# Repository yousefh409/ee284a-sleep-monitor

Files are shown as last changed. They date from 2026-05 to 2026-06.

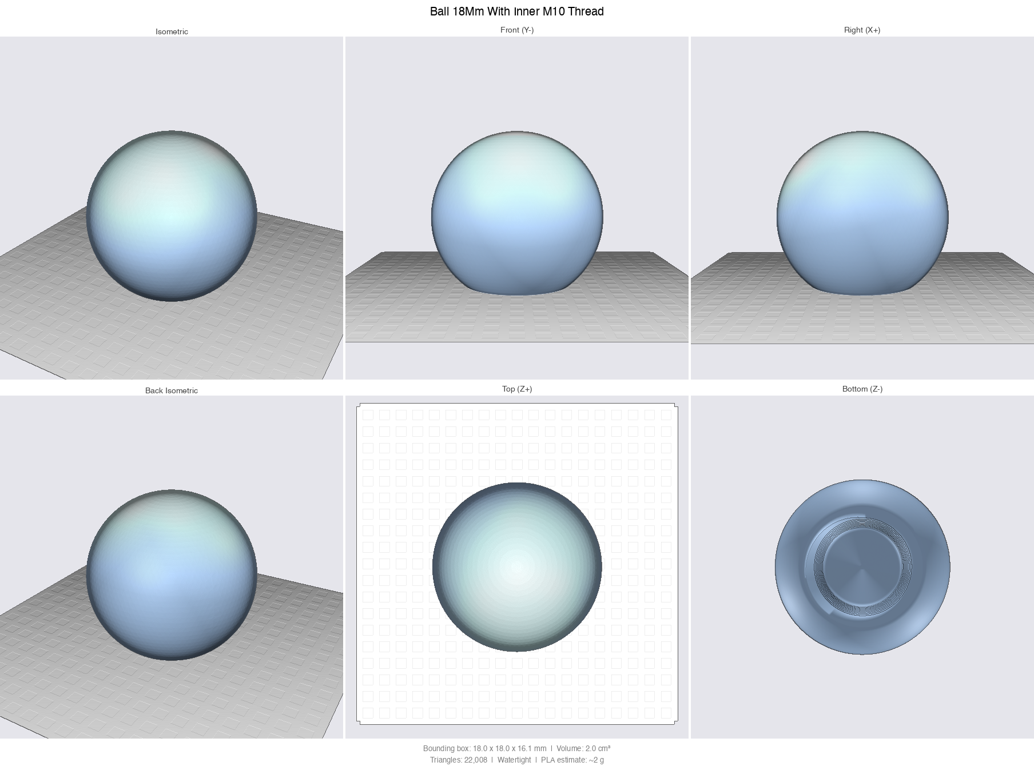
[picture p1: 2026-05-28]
cad/joint/Ball 18mm with inner M10 thread_preview.png

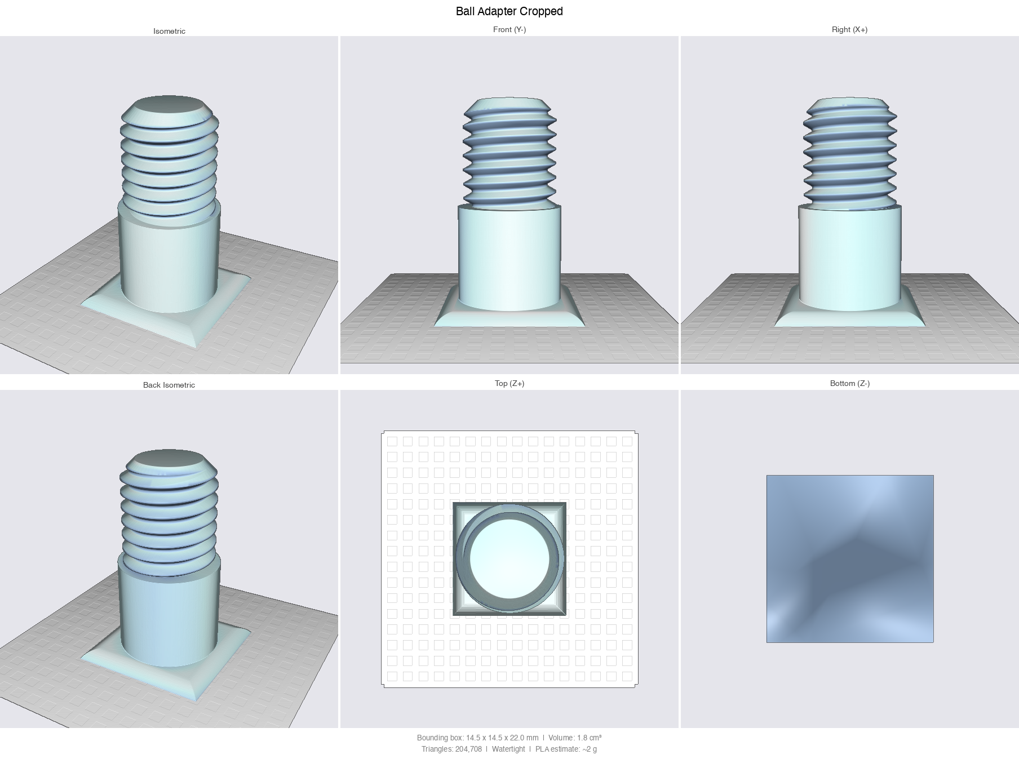
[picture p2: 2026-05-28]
cad/ball_adapter_cropped_preview.png

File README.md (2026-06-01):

# Sleep Monitor

**Contactless bedside sleep tracker that explains *why* you slept badly — no wearable required.**

A 60 GHz mmWave radar watches your breathing, heart rate, and sleep stages from across the room while environmental sensors log everything that could wake you. Each arousal gets tagged with its likely cause, and Claude writes you a morning briefing.

<p>
  
  
  
  
  
  
  
  
</p>

---

## Why

A third of adults sleep poorly, but consumer trackers demand nightly wearable compliance and still can't tell you *why* you woke up. This node sits on the nightstand, sees nothing but radar reflections and room conditions, and turns a night of raw telemetry into a plain-English explanation by morning.

## What it does

- **Contactless sleep staging** — awake / light / deep, with no wearable, from 0.4–2.5 m away
- **Live vitals in bed** — breathing rate and heart rate straight off the radar
- **Per-minute environment log** — temperature, humidity, pressure, gas/VOC air quality, noise (dB SPL), light
- **Annotated wake events** — every arousal tagged with its likely cause: noise spike, temperature drift, or light
- **AI morning briefing** — Claude turns the night into a sleep score, headline, wake-cause list, and 1–3 recommendations
- **Edge-side audio privacy** — raw mic samples never leave the device; only a computed dB SPL value is published

## How it works

```
USB-C wall ──> [Feather V2 ESP32] ──5V──> [C1001 60 GHz mmWave radar]
                       │  3V3
                       ├──I2C──> [BME680  temp/humidity/pressure/gas]
                       ├──ADC──> [SPW2430 mic  → on-device RMS → dB SPL]
                       └──ADC──> [Photoresistor  light]
                       │
                       └──Wi-Fi / MQTT / TLS──> [HiveMQ Cloud]
                                                      │
                                                      ▼
                                       [Next.js app on Railway]
                                         ├── MQTT subscriber (instrumentation.ts)
                                         ├── Postgres (telemetry / nights / reports)
                                         ├── Wake detection + correlation engine
                                         ├── Claude API → morning briefing
                                         └── Dashboard (Chart.js timeline)
```

The ESP32 publishes a ~350-byte JSON snapshot every 30 s. A single Next.js app subscribes over TLS, stores each row, and runs in-memory wake detection. When a sleep session ends it bundles the night, sends it to Claude, and stores a structured report the dashboard renders the next morning.

## Tech stack

| Layer | Stack |
|---|---|
| Firmware | PlatformIO · Arduino · ESP32 Feather V2 · PubSubClient · ArduinoJson |
| Sensing | DFRobot C1001 mmWave (UART) · BME680 (I²C) · SPW2430 mic + photoresistor (ADC) |
| Transport | MQTT over TLS · HiveMQ Cloud |
| Backend | Next.js 15 App Router · TypeScript · Postgres |
| AI | Anthropic Claude API (Haiku 4.5) with prompt caching |
| Dashboard | React · Tailwind CSS · Chart.js |
| Hosting | Railway (app + Postgres add-on) |

## Hardware (single node)

- Adafruit ESP32 Feather V2 (USB-C wall powered)
- DFRobot C1001 60 GHz mmWave radar — presence, sleep stages, breathing, heart rate
- BME680 — temperature, humidity, pressure, gas/VOC
- SPW2430 analog MEMS microphone + photoresistor (10 kΩ pull-down)
- 3D-printed enclosure + ball-joint wall mount (6 printed parts, see [PRINT-PLAN.md](PRINT-PLAN.md))

## Layout

| Folder | What |
|---|---|
| `firmware/` | PlatformIO project for the Feather V2 |
| `web/` | Next.js 15 app: MQTT subscriber + Postgres + Claude + dashboard |
| `cad/` | CadQuery scripts + STL files for the 3D-printed parts |
| `cad/final/` | The 6 STLs to print (numbered in build order) |

## Quick start

```bash
# Firmware — flash the Feather V2
cd firmware && pio run -t upload    # see firmware/README.md for config.h setup

# Web — local dev
cd web && npm install && npm run dev # see web/README.md for env vars + deploy
```

## Docs

- [PRD.md](PRD.md) — product requirements
- [TECH-SPEC.md](TECH-SPEC.md) — technical spec (firmware, MQTT, backend, dashboard)
- [DESIGN.md](DESIGN.md) — hardware design
- [WIRING.md](WIRING.md) — pin-by-pin wiring guide
- [CIRCUIT.md](CIRCUIT.md) — power + signal topology
- [PRINT-PLAN.md](PRINT-PLAN.md) — 3D print + assembly plan

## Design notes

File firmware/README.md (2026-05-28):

# Firmware

Adafruit ESP32 Feather V2 · PlatformIO · Arduino framework.

Two PlatformIO environments:

| Env | Source | What it does |
|---|---|---|
| `main` (default) | `src/main.cpp` | Production firmware: Wi-Fi → MQTT, publishes JSON to HiveMQ every 10 s. Needs `include/config.h`. |
| `sensor_test` | `src/sensor_test.cpp` | Bench test only: reads all sensors, prints one JSON line to USB serial every 1 s. No Wi-Fi, no MQTT, no config.h needed. |

## Setup (once)

Install [PlatformIO](https://platformio.org/install). VS Code extension recommended.

## Production build (main env)

```bash
cp include/config.h.example include/config.h
# edit include/config.h with Wi-Fi + HiveMQ credentials
pio run -e main -t upload
pio device monitor
```

## Sensor test (no credentials needed)

```bash
pio run -e sensor_test -t upload
pip install pyserial          # one-time
python3 serial_monitor.py     # auto-detects the port and pretty-prints
```

The `serial_monitor.py` script clears the terminal and re-renders the current sensor reading each second — easy to watch values change as you move/breathe in front of the C1001, cover the photoresistor, blow on the BME680, etc.

**Note:** the C1001 library has two hardcoded `delay(10000)` calls in its init + reset, so the first JSON line takes ~22 s after boot. Once running, JSON arrives every second.

See [../TECH-SPEC.md](../TECH-SPEC.md) for the full JSON schema.

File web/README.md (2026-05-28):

# Web

Next.js 16 (App Router) + Tailwind + Postgres + MQTT subscriber + Claude API.

Single app on Railway: MQTT subscriber runs inside `instrumentation.ts`, REST API in `app/api/`, dashboard in `app/page.tsx`.

## Local dev

1. Copy `.env.local.example` to `.env.local` and fill in credentials.
2. `npm run dev` → open `http://localhost:3000`. Schema is auto-applied on first request via `instrumentation.ts` → `lib/migrate.ts`.
3. First load redirects to `/login`. Use the password from `DASHBOARD_PASSWORD`.

## Layout

| Path | Purpose |
|---|---|
| `instrumentation.ts` | Boots the MQTT subscriber on Node.js runtime start |
| `proxy.ts` | Password gate (redirects unauthenticated requests to `/login`) |
| `lib/db.ts` | Postgres connection pool |
| `lib/mqtt.ts` | MQTT subscriber + telemetry insert + wake detection + LLM trigger |
| `lib/claude.ts` | Anthropic SDK wrapper, prompt-cached system prompt |
| `lib/schema.ts` | Postgres schema as a TS const (inlined for production) |
| `lib/migrate.ts` | Runs `SCHEMA_SQL` once on server boot (idempotent) |
| `lib/types.ts` | Shared TypeScript types |
| `app/page.tsx` | Dashboard (live panel + AI briefing + sleep-stage band) |
| `app/login/page.tsx` | Password gate UI |
| `app/api/login/route.ts` | POST `/api/login` — sets the session cookie |
| `app/api/live/route.ts` | GET `/api/live` — last 10 minutes of telemetry |
| `app/api/nights/route.ts` | GET `/api/nights` — list of past nights |
| `app/api/nights/[id]/route.ts` | GET `/api/nights/:id` — full night detail + report |
| `scripts/pub-test.mjs` | Local debug: publishes a synthetic telemetry payload to MQTT |

## Deploy to Railway

1. Push to a GitHub repo.
2. Create a Railway project, point it at this repo's `web/` folder.
3. Add the Postgres add-on. `DATABASE_URL` is auto-injected.
4. Set the rest of the env vars from `.env.local.example`.
5. Schema is auto-applied at startup; no manual migration step.

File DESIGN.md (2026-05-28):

# DESIGN: Sensor Node Hardware

**Companion to** [PRD.md](PRD.md) · **Date:** 2026-05-26

## 1. Enclosure

Wall-adhered housing with the C1001 mounted on the front via the ball-joint chain (joint plate → 18 mm ball → lock nut → cropped 3-leg adapter → L-bracket holder). Print and assembly details in [PRINT-PLAN.md](PRINT-PLAN.md).

## 2. Circuit Topology

```
USB-C wall ──> Feather V2 USB-C port
                Feather USB pin ──> C1001 (5V, GND)
                Feather 3V3 pin ──> BME680, mic, LDR
                Feather TX/RX  ──> C1001 UART
                Feather SDA/SCL ──> BME680
                Feather A2 ──> SPW2430 mic (analog)
                Feather A3 ──> Photoresistor + 10kΩ pull-down
```

No battery, no PMIC, no boost — Feather V2 directly powers everything from the USB-C wall.

## 3. Pin Map (Feather V2)

| Function | Pin | Notes |
|---|---|---|
| C1001 UART | TX / RX (Serial1) | 115200 baud; keeps USB serial free for debug |
| BME680 | SDA / SCL | I²C @ 0x77 (default, CS/SDO floating) — temp / humidity / pressure / gas |
| SPW2430 mic | A2 (ADC1) | Analog audio → onboard RMS → dB SPL |
| Photoresistor | A3 (ADC1) | With 10 kΩ pull-down |
| 5 V to C1001 | USB pin | Passthrough from USB-C wall power |

ESP32 ADC2 conflicts with Wi-Fi — both analog sensors are on ADC1 pins (A2, A3).

## 4. Open Items

- Mic dB SPL calibration constant — set during firmware bring-up by comparing to a phone SPL app under known sound levels.
- Cable routing from C1001 through the ball joint back to the breadboard — use a 4-wire cable, leave a small service loop.

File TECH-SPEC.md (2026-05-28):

# TECH-SPEC

**Project:** Contactless Sleep & Environment Monitor · **Date:** 2026-05-26
**Companion to:** [PRD.md](PRD.md) · [DESIGN.md](DESIGN.md) · [CIRCUIT.md](CIRCUIT.md) · [PRINT-PLAN.md](PRINT-PLAN.md)

## 1. Architecture

```
[Feather V2 ESP32]
   ├── C1001 mmWave (UART2)
   ├── BME680       (I2C 0x76)
   ├── SPW2430 mic  (ADC1 A2)
   └── Photoresistor(ADC1 A3)
            │
            └── Wi-Fi/MQTT/TLS ──> [HiveMQ Cloud]
                                        │
                                        ▼
                          [Next.js app on Railway]
                            ├── instrumentation.ts: MQTT subscriber
                            ├── Postgres (Railway add-on)
                            ├── Claude API (LLM analysis)
                            └── app/page.tsx: dashboard UI
```

Single Next.js app on Railway handles MQTT subscription, data storage, LLM analysis, REST API, and dashboard rendering. No separate worker, no separate frontend.

## 2. Hardware

**MCU:** Adafruit ESP32 Feather V2. USB-C wall powered. No battery, no PMIC, no boost.

**Sensors:**

| Sensor | Interface | Pin/Addr | Purpose |
|---|---|---|---|
| DFRobot C1001 60GHz mmWave | UART @ 115200 | TX2/RX2 | Presence, sleep stages, breathing, heart rate |
| BME680 | I2C @ 100kHz | 0x77 (default) | Temperature, humidity, pressure, gas/VOC resistance |
| SPW2430 MEMS mic | Analog | A2 (ADC1) | dB SPL (RMS computed on-device, raw audio never leaves) |
| Photoresistor + 10 kΩ | Analog | A3 (ADC1) | Light level |

Full wiring details in [CIRCUIT.md](CIRCUIT.md).

## 3. Firmware

**Platform:** PlatformIO, Arduino framework, `adafruit_feather_esp32_v2` board.

**Libraries:**
- `Adafruit_BME680` (+ `Adafruit_Sensor`)
- `DFRobot_HumanDetection` (C1001 driver)
- `PubSubClient` (MQTT)
- `ArduinoJson`
- `WiFiClientSecure` (TLS for HiveMQ)

**Wi-Fi credentials:** hardcoded in `firmware/include/config.h`, gitignored. Includes SSID, password, MQTT host, port, username, password, topic.

**Loop behavior:**

| Action | Cadence |
|---|---|
| Sample mic, compute 1 s RMS, update running max dB SPL | continuous |
| Read C1001 sleep composite (state, breathing, heart rate, presence) | 1 Hz |
| Read BME680 (T/H/P/gas) | 0.1 Hz (every 10 s); gas heater is 320 °C / 150 ms |
| Read photoresistor ADC | 0.1 Hz |
| Publish JSON to MQTT | every 10 s |

**Connection recovery:** Wi-Fi disconnect triggers reconnect loop. MQTT disconnect triggers reconnect loop.

## 4. MQTT

- **Broker:** HiveMQ Cloud Free (TLS, port 8883)
- **Topic:** `yousef/sleep01/telemetry`
- **QoS:** 1 (at-least-once delivery)
- **Retained:** false
- **Payload:** JSON, ~350 bytes

**JSON schema (per-minute snapshot, all values nullable if sensor not in a valid state):**

```json
{
  "t": 1735689600,
  "dev": "sleep01",

  "presence": 1,
  "in_bed": 1,
  "sleep_state": 2,
  "breathing": 16,
  "heart_rate": 62,
  "turnover": 14,
  "body_move_large": 4,
  "body_move_small": 22,
  "apnea_events": 0,

  "temp_c": 22.1,
  "humidity": 45.2,
  "pressure_hpa": 1013.2,
  "gas_ohm": 5684,
  "db_spl": 32.5,
  "light_raw": 245
}
```

| Field | Source | Units | Notes |
|---|---|---|---|
| `t` | ESP32 | unix seconds | NTP-synced |
| `presence` | C1001 composite | 0/1 | Anyone in detection cone |
| `in_bed` | C1001 `smSleepData(eInOrNotInBed)` | 0/1 | More specific than presence |
| `sleep_state` | C1001 composite | 0–3 | 0 not-in-bed, 1 awake, 2 light, 3 deep |
| `breathing` | C1001 composite `averageRespiration` | breaths/min | Recent average |
| `heart_rate` | C1001 composite `averageHeartbeat` | bpm | Recent average |
| `turnover` | C1001 composite `turnoverNumber` | count | Cumulative for current session |
| `body_move_large` | C1001 composite `largeBodyMove` | % | Recent window large-motion fraction |
| `body_move_small` | C1001 composite `minorBodyMove` | % | Recent window small-motion fraction |
| `apnea_events` | C1001 composite `apneaEvents` | count | Cumulative for current session |
| `temp_c` | BME680 | °C | |
| `humidity` | BME680 | % RH | |
| `pressure_hpa` | BME680 | hPa | |
| `gas_ohm` | BME680 | Ω | Gas/VOC sensor resistance; lower = more VOCs/contaminants |
| `db_spl` | SPW2430, RMS over 1 s | dB SPL approx | Max over last 10 s |
| `light_raw` | Photoresistor | 0–4095 | ADC raw, calibrate to lux dashboard-side |

**Session-level fields** (queried from C1001's `getSleepStatistics()` at end-of-session only, written directly to Postgres `nights` table, NOT in per-minute MQTT): `sleepQualityScore`, `sleepTime`, `wakeDuration`, `shallowSleepPercentage`, `deepSleepPercentage`, `timeOutOfBed`, `exitCount`, `turnOverCount`. These feed the AI briefing alongside the raw telemetry.

## 5. Backend (Next.js)

**Framework:** Next.js 15 App Router, TypeScript.

**MQTT subscriber:** in `instrumentation.ts`, runs once on server boot. Uses `mqtt` npm package, holds persistent TLS connection to HiveMQ. On each message: parse JSON, insert row into Postgres, run wake-detection check.

**Wake detection:** maintains in-memory state per device. A "sleep session" starts when `presence=1` AND `sleep_state >= 2` for 5 consecutive minutes. A session ends when `presence=0` for 5 consecutive minutes after such a start, or when `sleep_state` is `1` (awake) for 10 consecutive minutes after a long-enough session (>2 h). On session end: bundle the session's telemetry, send to Claude, store the report.

**Postgres schema:**

| Table | Columns |
|---|---|
| `telemetry` | id, device, ts, presence, in_bed, sleep_state, breathing, heart_rate, turnover, body_move_large, body_move_small, apnea_events, temp_c, humidity, pressure_hpa, gas_ohm, db_spl, light_raw |
| `nights` | id, device, started_at, ended_at, duration_sec, sleep_score |
| `reports` | id, night_id, headline, sleep_score, stage_pct (jsonb), vitals (jsonb), wake_events (jsonb), recommendations (jsonb), generated_at |

`telemetry` is indexed on `(device, ts)`. `nights` is indexed on `(device, started_at DESC)`.

**Claude API integration:** Anthropic SDK (`@anthropic-ai/sdk`). On wake-detection trigger:

1. Query `telemetry` rows for the night.
2. Downsample to ~1 row per minute, serialize as CSV.
3. Send to Claude Haiku 4.5 with a fixed system prompt: "You are a sleep coach analyzing one night of contactless monitor data." (Upgrade path to Sonnet 4.6 by changing one env var if Haiku output is insufficient.)
4. Parse Claude's structured JSON response.
5. Insert into `reports`.

**Prompt caching:** the system prompt + the schema description are cached (5 min TTL) so consecutive analyses pay only for new telemetry.

**REST endpoints:**

| Route | Returns |
|---|---|
| `GET /api/nights` | list of nights with date, score, headline |
| `GET /api/nights/[id]` | full night payload: report + downsampled telemetry |
| `GET /api/live` | last 10 minutes of telemetry rows |

**Auth:** simple password gate via Next.js middleware. Single password from `DASHBOARD_PASSWORD` env var. Sets a signed session cookie on success.

## 6. Dashboard

**Stack:** Next.js + React + Tailwind CSS + Chart.js. Calm health-app aesthetic.

**Page structure (`app/page.tsx`):**

1. **Top bar:** date picker dropdown (recent nights), connection status indicator (live), logout button.
2. **Live panel** (when current night ongoing): last 10 minutes of breathing, heart rate, dB, temp. Polls `/api/live` every 5 seconds.
3. **AI morning briefing card:**
   - Sleep score (big number) + headline
   - Stage breakdown (% awake / light / deep) + vitals (avg breathing, avg HR)
   - Wake events list with timestamps and environmental causes
   - 1-3 recommendations for tonight
4. **Charts (below briefing):**
   - Overnight sleep-stage band (Chart.js timeline)
   - Breathing + heart rate dual-line
   - Environmental overlay (temp, humidity, dB, light) with wake-event markers
5. **Footer:** link to PRD/repo.

**Live refresh:** `setInterval(fetch, 5000)` polling the `/api/live` endpoint.

## 7. Edge efficiency

Wall-powered means no hard runtime constraint, but the firmware still implements meaningful power-management techniques. Measured + reported as innovation #5 even without a battery.

| Technique | Behavior | Approx saving |
|---|---|---|
| ESP32 light-sleep between samples | Between sensor reads, MCU drops to ~3 mA. Wakes on RTC timer for next sample. | ~70% of MCU draw |
| Wi-Fi modem-sleep | Modem off between MQTT publishes; wakes only to TX. Keep-alive set to 60 s. | ~50% of radio draw |
| C1001 soft-stop on long absence | If `presence=0` for >30 minutes, send `stop` command over UART. Resume on next motion event. | ~100 mA → ~idle when room empty |
| BME680 forced mode | One-shot reads instead of continuous; sleeps between reads. | ~99% of BME draw between samples |
| Mic sampling burst | 1 s of 8 kHz ADC reads per 10 s, then ADC idle. | ~90% of ADC duty |

**Measured baseline target:** ~80 mA average system current (vs ~150 mA naive always-on). Not battery-critical but documents good IoT design and gives the report something concrete to point at.

## 8. Deployment

| Service | Provider | Setup |
|---|---|---|
| MQTT broker | HiveMQ Cloud Free | Signup, create free cluster, copy host + credentials |
| App + worker | Railway | `railway up` from this repo, sets PORT |
| Postgres | Railway add-on | One-click attach, `DATABASE_URL` auto-injected |

**Env vars (Railway):**
- `DATABASE_URL` (auto)
- `MQTT_HOST`, `MQTT_PORT`, `MQTT_USER`, `MQTT_PASS`, `MQTT_TOPIC`
- `ANTHROPIC_API_KEY`
- `DASHBOARD_PASSWORD`

**Local Wi-Fi config (firmware):** `firmware/include/config.h` (gitignored):
- `WIFI_SSID`, `WIFI_PASS`
- Same MQTT credentials as the Railway service uses to subscribe.

## 9. Demo plan

**Live (1 min):**
1. Power on the device. Connection state visible on the dashboard ("● streaming" indicator).
2. Walk past it, sit on a chair in front of it. Dashboard live panel shows presence flipping to 1 and breathing rate appearing.
3. Open the dashboard live panel on screen.

**Recorded (5 min):**
1. Open the date picker. Select a prior real overnight dataset.
2. Walk through the AI briefing card: sleep score, headline, wake events, recommendations.
3. Scroll to charts. Point at a wake event marker, show the environmental spike that caused it.
4. Mention all 6 innovations as they appear visually.

**Innovations recap (also on slides):**
1. New sensor type not in prior labs: C1001 60GHz mmWave radar (presence + sleep stages + breathing + heart rate onboard)
2. Multi-sensor correlation engine (radar wake events linked to env spikes ±60 s)
3. AI-driven sleep coach (Claude API auto-generates morning briefing on wake)
4. Custom consumer-facing dashboard
5. 3D-printed wall-mount enclosure + ball-joint chain (housing + L-bracket holder + cropped community joint)
6. Edge-side audio privacy (raw mic samples never leave the device; only dB SPL transmitted)
7. Edge efficiency (light-sleep, modem-sleep, C1001 soft-stop on absence; measured ~50% avg current reduction)

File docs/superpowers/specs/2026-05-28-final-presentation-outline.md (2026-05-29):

# Final Presentation Outline — Contactless Sleep & Environment Monitor

**Course:** EE284A · **Author:** Yousef Helal · **Demo day:** 2026-06-09
**Format:** 25 min total = 15 min talk + 10 min live demo + 5 min Q&A

## Framing decisions
- **Application domain:** Healthcare → eldercare (senior-living facilities).
- **Narrative arc:** introduce the large-scale eldercare vision first, then the single node actually built.
- **Talk/demo order:** deliver the full talk (slides 1–15), then go live for the demo, then Q&A. Narrative concludes before the demo so a demo hiccup can't undercut the close.

## Slide list

| # | Slide | Job |
|---|---|-----|
| 1 | Title | Contactless Sleep & Environment Monitor · eldercare framing · author · EE284A. (Optional cold-open on the statistic instead.) |
| 2 | Hook | Hard statistic — sleep as a health monitor / early-warning signal in older adults |
| 3 | Problem | Comparison table: wearables vs clinical sleep study vs cameras vs this system — only this system checks every box (compliance-free, low-cost, private, continuous) |
| 4 | Solution reveal | The single idea: passive contactless bedside monitor, nothing to wear + one value-prop line + device image |
| 5 | Eldercare vision | Node per resident room → central nursing-station dashboard + prioritized alerts; "greater than the sum of its parts" (one nurse watches a wing, cross-resident baselines, triage) |
| 6 | System architecture | N nodes → Wi-Fi → MQTT broker → cloud services (correlator + storage) → caregiver dashboard; security & management as labeled callouts |
| 7 | Node overview | Annotated hero photo of the real built device, callouts on every component |
| 8 | Hardware: radar | DFRobot C1001 60 GHz mmWave — FMCW micro-motion → breathing/heart rate + onboard sleep stages; why radar = contactless + private; UART / 5 V |
| 9 | Hardware: sensors + wiring | BME680 (I²C), SPW2430 mic (ADC), photoresistor (ADC); block/wiring diagram |
| 10 | Hardware: enclosure | 3D-printed ball-joint enclosure render with feature callouts (innovation #4) |
| 11 | Software: edge | ESP32 firmware + MQTT + on-device dB SPL (RMS); raw audio never leaves the device; per-minute JSON payload |
| 12 | Software: cloud | Correlation engine — "why you woke up": joins radar wake events with environmental spikes within ±60 s and labels the cause |
| 13 | Results: overview | Real overnight dataset on the dashboard — full-night view (sleep-stage bands + environment overlay + sleep score) |
| 14 | Results: zoom | One annotated correlated wake event |
| 15 | Innovations scorecard | 5 innovations mapped to the assignment's categories (sensor / data processing / visualization / physical design) — 4 of 5 categories hit |
| 16 | Impact + future | Short/long-term eldercare impact + honest roadmap (fall detection, multi-person beds, ML scoring, multi-node home networks) |
| — | **LIVE DEMO** | 10 min — interactive dashboard playback + live MQTT publish |
| 17 | Questions? | Shown during the 5-min Q&A after the demo |

## Five technical innovations (referenced on slide 14)
1. New sensor: C1001 60 GHz mmWave radar (onboard sleep stages + breathing + heart rate)
2. Multi-sensor cloud correlation engine (wake event ↔ environmental cause)
3. Custom web dashboard (overnight timeline + environment overlay + annotated wake causes)
4. 3D-printed wall-mount enclosure with ball-joint aim
5. Edge-side audio privacy (on-device RMS → dB SPL; no raw audio transmitted)

## Rubric coverage check
- Application domain + proposed system → slides 1–5
- Motivation + background → slides 2–3
- System design overview → slides 5–6
- Implementation + results → slides 7–13
- Expected system impact + conclude → slide 15
- Technical innovation requirement → slide 14 (woven through 8–11)
- Live sensor-node demo on MQTT → live demo segment

## Per-slide content (in progress)

### Slide 1 — Title
- Name + tagline (e.g., "Contactless Sleep & Environment Monitor" + "Passive sleep & vitals — nothing to wear"). Details deferred.

### Slide 2 — Hook (hard-clinical stat trio)
Three beats: common → dangerous → invisible. All three verified against primary/strong sources (2026-05-28).

- **Common — 42%:** In a study of >9,000 community-dwelling adults aged 65+, 42% reported difficulty initiating and maintaining sleep.
  - Source: Foley DJ et al., "Sleep complaints among elderly persons: an epidemiologic study of three communities," *Sleep* 1995;18(6):425–432. Landmark/foundational figure.
  - Links: https://academic.oup.com/sleep/article/18/6/425/2749669 · https://pubmed.ncbi.nlm.nih.gov/7481413/
- **Dangerous — 27%:** "Each percentage decrease in deep sleep each year was associated with a 27% increase in the risk of dementia."
  - Source: JAMA Neurology (2023) study, Framingham Heart Study cohort (Himali et al.). Accessible explainer: Medical News Today.
  - Link: https://www.medicalnewstoday.com/articles/not-getting-enough-deep-sleep-may-increase-dementia-risk
- **Invisible — 38%:** "One-quarter screened positive for chronic insomnia (N = 117); yet, only 44 (38%) had an EHR-documented insomnia diagnosis."
  - Source: "Novel Approaches for Early Detection of Chronic Insomnia Among Older Primary Care Patients," PMC.
  - Link: https://pmc.ncbi.nlm.nih.gov/articles/PMC12761964/
- Takeaway line: sleep problems are common, serious, and largely unmeasured — that gap is what a passive monitor fills.
- Note: the 42% figure is from 1995 (canonical but old); if a more recent prevalence number is preferred, AAFP gives "up to 40% of older adults have insomnia" and "45% in persons 65–79" (https://www.aafp.org/pubs/afp/issues/2013/0215/p280.html).

### Slide 3 — Problem (comparison table)
- Rows: consumer/medical wearable · clinical sleep study (PSG) · camera/audio monitor · **this system**.
- Columns: Passive (no wearable) · Continuous (every night) · Private · **Identifies environmental cause**.
- Check pattern: wearable fails Passive; sleep study fails Continuous; camera fails Private; only this system checks all four. (Camera checking passive+continuous but failing private is a deliberate contrast.)

### Slide 4 — Solution reveal
- Hook headline: **"Knows how you slept — and why."** Pays off the env-cause column.
- One value-prop line: passive contactless bedside monitor that tracks sleep + vitals and the room conditions around you, correlating each disruption to its cause — nothing to wear.
- Visual: device render/photo.

### Slide 5 — Eldercare vision (greater than the sum of parts)
- Deployment: senior-living facility; node per resident room → central nursing-station dashboard + prioritized alerts.
- Headline emergent benefit: **passive triage at scale** — one nurse monitors a whole wing; alerts surface who needs attention tonight.
- Supporting benefits (speak): per-resident trends → early decline detection; facility-wide patterns (HVAC/heat degrading a whole wing).
- Visual: **1 → N emergent-value diagram** (one node's data vs the network's aggregate insights).

### Slide 6 — System architecture
- Scope: large-scale conceptual — N nodes → Wi-Fi → MQTT broker → cloud services (correlator + storage) → caregiver dashboard. As-built single-node pipeline appears later (slides 10–11).
- Visual callout: **privacy by design (no raw audio/video)**.
- Speak for rubric (not visual callouts): TLS + per-device auth on MQTT, OTA updates + device-health/heartbeat monitoring.

### Slide 7 — Node overview
- Annotated hero photo of the real device; callouts: C1001 mmWave radar, BME680, SPW2430 mic, photoresistor, ESP32 Feather V2, status LED, push button, 3D-printed enclosure.
- At-a-glance spec strip: USB-C powered · Wi-Fi/MQTT · ~6 environmental channels (temp/humidity/pressure/gas/dB/light) + radar-derived vitals · per-minute telemetry. (Confirm exact channel count/wording.)

### Slide 8 — Hardware: radar (headline innovation)
- Approach: intuition-first — 60 GHz radar detects sub-millimeter chest micro-motion → breathing & heart rate; onboard algorithm classifies presence + sleep stages.
- One FMCW credibility line (chirp + reflected-signal phase tracks micro-motion).
- Why radar: private (no camera), works in the dark, sees through bedding/clothing.
- Interface notes: UART to ESP32, 5 V; chest range ~0.4–2.5 m (placement constraint).

### Slide 9 — Hardware: supporting sensors + wiring
- Sensors: BME680 (I²C → temp/humidity/pressure/gas-VOC air quality), SPW2430 analog MEMS mic (ADC → noise), photoresistor + 10 kΩ pull-down (ADC → light).
- Presentation: **block/wiring diagram hero** — ESP32 Feather V2 at center, three sensors + status LED + push button wired in, I²C bus and ADC channels labeled; power rails (USB-C 5 V → radar, 3V3 → sensors).

### Slide 10 — Hardware: enclosure (innovation #4)
- Single clean enclosure **render with feature callouts** (minimal text).
- Callout targets: sensor window, joint plate, 18 mm ball-joint, lock nut, C1001 L-holder, housing cavity, wall-mount back face.
- (Context, spoken if asked: ball-joint solves the narrow radar aim window on a wall mount; parametric CAD; reused proven community M10 threads.)

### Slide 11 — Software: edge / firmware
- Presentation: edge flow diagram (sensors → on-device processing → per-minute JSON → MQTT) + an actual sample payload.
- Headline: **edge audio privacy (innovation #5)** — ESP32 computes dB SPL via on-device RMS; raw audio never leaves the device.
- Secondary: per-minute JSON aggregation as a data-processing efficiency (many samples → one small payload).
- Build note: drop in the real firmware JSON schema/keys when making the slide.

### Slide 12 — Software: cloud correlation engine (innovation #2)
- Presentation: **worked-example timeline** — one real wake event; show the ±60 s window catching an environmental spike; output a labeled cause (noise / temp drift / light).
- Message: this is what makes the dashboard explain *why* you woke, not just *that* you did. On-ramp into the results slides.

### Slide 13 — Results: full-night overview
- Real overnight dataset screenshot, framed as an **annotated night**: full timeline with sleep-stage bands + environment overlay, all wake events marked with their causes.
- Pick the cleanest real night collected at home.

### Slide 14 — Results: zoom
- Zoom into the **single cleanest correlation** — one crisp wake event with an obvious cause (e.g., noise spike → arousal), fully annotated.

### Slide 15 — Innovations scorecard (4 of 5 categories)
- Grid of the assignment's 5 categories:
  - Sensors → C1001 60 GHz mmWave radar ✓
  - Data Processing → edge dB SPL (on-device) + cloud correlation engine ✓
  - Data Visualization → custom dashboard ✓
  - Physical Design → 3D-printed ball-joint enclosure ✓
  - Power Management → not pursued (USB-C wall powered) ✗
- Headline: 4 of 5 categories hit (honest).

### Slide 16 — Impact + future (today → tomorrow split)
- **Today (one node, one room):** passive contactless sleep + vitals, zero compliance, explains disruptions, privacy by design.
- **Tomorrow (facility scale):** fleet triage, early decline detection, fall detection, multi-person beds, ML sleep scoring, battery/portable, aging-in-place.

### Slide 17 — Questions?
- Minimal — just "Questions?". Shown during Q&A.

### Live demo (10 min) — not yet planned
- Defer to PRD success criteria: live node publishing to MQTT + dashboard playback of a real overnight dataset with annotated wake events. Flow/script TBD by author.

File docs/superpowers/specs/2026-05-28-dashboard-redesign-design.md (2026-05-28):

# Dashboard Redesign — Design Spec

**Date:** 2026-05-28
**Scope:** Full overhaul of `web/app/page.tsx` and supporting components.

## Goal

Replace the current "live monitor + selectable night detail" dashboard with a single-night viewer anchored on **last night's stats**, navigated by a calendar heatmap popover and prev/next arrows. Drop the dedicated live view (live data continues ingesting and shows up on charts naturally). Establish a coherent visual language built on a bookish × mineral mood.

## Information architecture

- **One route, one page.** No sub-pages. The night view is the page.
- **Default selection:** the most recent completed night in the `nights` table (i.e. "last night").
- **Navigable slots:** every completed night (one per row in `nights`), plus a synthetic **today-in-progress slot** for the current PST date when no completed night row exists for that date.
- **Night → calendar date mapping:** a night maps to the PST date of its `started_at`. The today-in-progress slot maps to the current PST date.
- **Navigation:**
  - Prev/next arrows step through the ordered slot list (completed nights + today-in-progress when applicable). They skip past days that have no data. They are disabled at the first/last available slot.
  - Forward from "last night" lands on the today-in-progress slot when it exists.
  - The date label between the arrows is a button that opens the heatmap calendar popover.
- **All current content is preserved**, restructured for clearer hierarchy.

## Page structure (top to bottom)

1. **Header strip.** `← [Wed, May 27 ▾] →`. A small `● in progress` pill appears on the right when the selected slot is the today-in-progress slot.
2. **Hero.** Sleep score as the dominant element — very large, light weight, copper-tinted. Editorial headline beside or below it. Generous whitespace.
3. **At-a-glance stats row.** Five stats: awake %, light %, deep %, avg breathing, avg heart rate. Label-over-value pairs, no boxes — type hierarchy carries it.
4. **Sleep-stage timeline band.** Full-width colored strip (existing `StageBand`) using the new stage palette. Hour markers underneath.
5. **Two-column block: wake events (left) + recommendations (right).** Side-by-side on desktop, stacked on mobile. Typed lists, no card chrome.
6. **Charts (stacked).**
   - Vitals (heart rate + breathing)
   - Environment (temperature + humidity)
   - Audio + light
   Each scoped to the selected night's window. Section label above (uppercase eyebrow), no card surface.
7. **Raw telemetry table.** Collapsed by default behind a "Show raw data" toggle. When expanded, it sits on a slightly raised surface and contains the full 40-field filterable table.

## Calendar popover

- Trigger: click the date button in the header. Dismiss on outside click or Esc.
- Anchored to the date button, ~320px wide, single-month view.
- **Header:** month/year label with `‹ ›` to navigate months. "Today" link in the corner jumps back to the current month.
- **Grid:** 7 columns, **Mon → Sun**. Each cell is a square showing the day number in the top-left corner.
- **Heatmap fill:** copper at varying opacity (roughly 5 tints) based on sleep score. Days with no data have a transparent cell and a light-gray day number. The today-in-progress slot renders with a thin pulsing copper ring (no fill) instead of a heatmap color.
- **Selected day:** outlined with a thin ink-colored ring (no fill change, to preserve heatmap reading).
- **Hover:** subtle ring + tooltip showing date and score (e.g. "Wed, May 27 · 82"). Days with no data show "No data" and the click is a no-op.
- **Out-of-month days:** faded, but clickable if they have data.
- **Click on a data day:** loads that night and closes the popover.

## Edge cases

- **No-data day clicked:** popover stays open; cell shows "No data" tooltip; click is a no-op.
- **Prev/next at boundaries:** arrows disable (fade) at the first or last available slot.
- **Today-in-progress slot:**
  - Exists whenever the current PST date has no completed `nights` row. Detected purely from PST time + the `nights` table — no telemetry-recency check required.
  - `● in progress` pill in the header.
  - Hero score renders "—" with an "in progress" label beneath. No headline.
  - Stats row, stage band, wake events, recommendations: render whatever can be computed from today's telemetry; missing fields show "—".
  - Charts: scoped to today's PST window (00:00 → now). When no telemetry exists yet for today, charts render an empty-state placeholder.
  - Raw telemetry table: shows today's rows.
- **Empty state (no completed nights and no telemetry today):** the entire page is replaced with a single empty state — "Waiting for your first night" plus a faint device icon.
- **Loading state:** skeleton blocks matching the hero + stats layout, copper-tinted shimmer.

## Visual language

### Mood

Bookish × mineral blend. Warm, grounded, editorial. Quiet authority with one earned accent color.

### Color tokens

| Token | Value | Role |
|---|---|---|
| `--ground` | `#F5F1E8` | Page background (plaster cream) |
| `--ground-raised` | `#FFFFFF` | Raised surface (only used by the expanded telemetry table) |
| `--ink` | `#1A1815` | Primary text (warm near-black) |
| `--ink-muted` | `#5C574F` | Secondary text (warm-tinted weathered slate) |
| `--rule` | `#E5DFD2` | Hairlines, dividers |
| `--copper` | `#8B6F47` | Primary accent (oxidized copper, muted) |
| `--copper-soft` | `rgba(139, 111, 71, 0.15)` | Chart fills, heatmap pale steps |
| `--stage-out` | `#EBE5D6` | Sleep stage: out of bed |
| `--stage-awake` | `#C9C0AC` | Sleep stage: awake |
| `--stage-light` | `#7A7468` | Sleep stage: light sleep |
| `--stage-deep` | `#1A1815` | Sleep stage: deep sleep |

Heatmap scale: 5 steps from low → high sleep score, derived from `--copper` by varying opacity/saturation.

### Type scale (Geist Sans + Geist Mono, already loaded)

| Role | Family | Weight | Size | Tracking | Line height |
|---|---|---|---|---|---|
| Display (sleep score) | Geist Sans | 200 | ~120px | -0.04em | 1.0 |
| Editorial headline | Geist Sans | 500 | ~28px | -0.01em | 1.2 |
| Section label / eyebrow | Geist Sans | 500 | 11px | +0.08em | 1.2 (uppercase) |
| Body / list | Geist Sans | 400 | 15px | 0 | 22px |
| Stat label | Geist Sans | 500 | 11px | +0.08em | 1.2 (uppercase) |
| Stat value | Geist Sans | 400 | 22px | -0.01em | 1.2 |
| Mono (timestamps, numerics) | Geist Mono | 400 | 13px | 0 | 1.4 |

## Chart styling

- No card chrome. Charts sit directly on `--ground` with only a section label above.
- Primary series stroke: `--copper`. Secondary series: `--ink-muted`.
- Axes: hairline `--rule`. Axis labels in Geist Mono, `--ink-muted`.
- Hover: thin `--ink` crosshair plus a small ink-on-cream tooltip card.
- Gridlines: drop most. Keep only the baseline and at most one or two value lines.
- **Vitals chart:** heart rate (copper) + breathing (ink-muted) on a shared axis.
- **Environment chart:** temperature (copper) + humidity (ink-muted) on a dual axis.
- **Audio/light chart:** dB (copper) area or bars + light (ink-muted) line.
- **Sleep stage band:** structurally unchanged; uses the new stage palette.
- **Telemetry table (collapsed by default):** sits on `--ground-raised` when expanded; mono font; hairline row borders in `--rule`.

## Components and boundaries

The redesign reorganizes responsibilities so each component has one job and a clean interface. Files to add or change in `web/app`:

- `components/NightHeader.tsx` — header strip with prev/next arrows, the date popover trigger, and the in-progress pill. Owns the disabled-state logic for arrows.
- `components/CalendarPopover.tsx` — the heatmap calendar popover. Receives the slot list (nights + today-in-progress) and the selected date; emits a date selection.
- `components/NightHero.tsx` — the big sleep score + headline block. Handles the in-progress variant ("—" score, no headline).
- `components/StatsRow.tsx` — the five at-a-glance stats. Renders "—" for missing values.
- `components/StageBand.tsx` — existing, restyled with new stage palette.
- `components/WakeEvents.tsx` — list of wake events.
- `components/Recommendations.tsx` — list of recommendations.
- `components/LiveCharts.tsx` — existing; restyled (no card chrome, copper accent, hairline axes).
- `components/TelemetryTable.tsx` — existing; collapsed by default behind a toggle.
- `components/EmptyState.tsx` — "Waiting for your first night" screen.
- `app/page.tsx` — slim orchestrator: fetch the nights list and the selected night detail, render the components.
- `app/globals.css` — define the color tokens and base typographic rhythm.

## Data and API

Minor backend changes are required.

- `GET /api/nights` — bump the `LIMIT 30` to `LIMIT 365` so the calendar heatmap can show ~12 months of history. Response shape unchanged: id, started_at, ended_at, duration_sec, sleep_score, headline. Used to color heatmap cells and to determine prev/next neighbors.
- `GET /api/nights/:id` — extend the telemetry aggregation query so the per-minute rows include **all 40 telemetry fields**, not just the 8 it currently averages. Field set matches the live endpoint. Used to render the hero, stats, stage band, wake events, recommendations, charts, and the raw telemetry table.
- `GET /api/today` (new) — returns today's telemetry rows for the today-in-progress slot. Aggregated per minute, all 40 fields. Window is PST 00:00 → now. The client uses this whenever the user navigates to the in-progress slot. Implementation can reuse the same aggregation logic as `/api/nights/:id`.
- `GET /api/live?minutes=N` — no longer used by the UI; kept for the `/api/export` flow and for backwards compatibility. Not removed in this redesign.

**Slot identifier in the URL.** Selection state lives in a query param: `/?d=YYYY-MM-DD` (PST date). The client maps date → night row (or today-in-progress slot). Default with no query is "last night" (the most recent completed `nights` row). A specific date is shareable and deep-linkable.

## Out of scope

- New telemetry fields or schema changes.
- Authentication or user-account changes.
- Mobile-native apps. Layout is responsive but stays a single web page.
- Multi-device support beyond the existing `device` query param.
- Per-night editing, notes, or sharing features.

## Success criteria

- Landing on `/` shows last night's full detail without any clicks.
- The date button opens a calendar heatmap where score patterns are visible at a glance.
- Prev/next arrows step between slots (completed nights + today-in-progress when applicable) and disable at boundaries.
- All current content from the existing dashboard remains accessible (charts, table, briefing, wake events, recommendations).
- The page reads as one coherent visual system — bookish/mineral mood, copper accent used sparingly, editorial type hierarchy.
- The today-in-progress slot, no-data-day, and no-nights edge cases each have intentional handling.
- The today-in-progress slot is reachable by pressing the forward arrow from "last night".

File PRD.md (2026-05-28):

# PRD: Contactless Sleep & Environment Monitor

**Course:** EE284A · **Author:** Yousef Helal · **Date:** 2026-05-26 · **Demo:** 2026-06-09

## Problem
A third of adults sleep poorly, but consumer sleep trackers require nightly wearable compliance and can't explain *why* sleep was disrupted. Clinical-grade alternatives are expensive and intrusive.

## User
Sleep-conscious adults who want passive, no-wearable tracking that explains disruptions in the morning.

## Solution
A bedside IoT node combining a 60 GHz mmWave radar (presence + sleep stages + breathing/heart rate) with environmental sensors (temperature, humidity, pressure, air quality, noise, light). USB-C wall powered. Publishes per-minute telemetry over Wi-Fi/MQTT. A cloud-side correlation engine annotates each wake event with its most likely environmental cause, surfaced on a morning dashboard.

## Key Features
- Contactless sleep-stage tracking (awake / light / deep) without wearables
- Live breathing rate and heart rate while in bed (chest distance 0.4–2.5 m)
- Per-minute environmental log: temperature, humidity, pressure, gas/VOC air quality, dB SPL, light level
- Annotated wake events: each arousal tagged with likely cause (noise / temp drift / light)
- Morning dashboard: overnight timeline + sleep score + correlated environment overlay

## Architecture
```
USB-C wall ──> [Feather V2 ESP32] ──5V──> [C1001 mmWave]
                       │  3V3
                       ├──I2C──> [BME680]
                       ├──ADC──> [SPW2430 mic]  (raw audio computed on-device → dB SPL)
                       └──ADC──> [Photoresistor]

   Feather V2 ──Wi-Fi──> [MQTT broker] ──> [Cloud worker: correlator] ──> [Web dashboard]
```
Raw audio never leaves the device; the ESP32 computes RMS over a 1 s window and publishes only the dB SPL value. Per-minute JSON payload over MQTT.

## Bill of Materials (single node)
- Adafruit ESP32 Feather V2
- DFRobot C1001 60 GHz mmWave radar (5 V, UART)
- BME680 (I²C @ 0x76)
- SPW2430 analog MEMS microphone
- Photoresistor + 10 kΩ pull-down
- Full-size breadboard (165 × 55 mm) + jumper wires
- 3D-printed enclosure + ball-joint mount (see PRINT-PLAN.md)
- USB-C wall adapter

## Technical Innovations (4)
1. **New sensor:** DFRobot C1001 60 GHz mmWave radar (not used in prior labs; onboard sleep stages + breathing + heart rate)
2. **Multi-sensor correlation engine:** cloud logic that joins radar wake events with environmental spikes within ±60 s and labels the cause
3. **Custom web dashboard:** overnight timeline with sleep-stage bands + environmental overlay + annotated wake-cause markers
4. **3D-printed wall-mount enclosure with ball-joint aim:** custom housing + L-bracket holder + cropped community ball-joint chain lets the C1001 be aimed at the bed regardless of wall position
5. **Edge-side audio privacy:** raw microphone samples never leave the device — on-board RMS → dB SPL computation means the dashboard sees only the noise level, never an audio recording

## Success Criteria (Demo Day)
- Live: node publishes presence, breathing rate, dB, temp, light to MQTT in real time
- Recorded: dashboard plays back ≥1 full real overnight dataset collected at home, with annotated wake events
- All 5 innovations visibly demonstrated within the 25-minute window

## Out of Scope (v1)
- Multi-person bed tracking · cloud-side ML training · mobile app · long-term trend analytics · multi-node home networks · battery / portable operation

## Risks
- C1001 chest range (0.4–2.5 m) constrains enclosure placement — mitigate with 3D-print testing in week 1
- Real overnight data collection needs ≥3 usable nights before June 7 — start by end of week 1
- dB SPL calibration is approximate without a reference meter — acceptable for relative spike detection

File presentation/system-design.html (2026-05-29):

Nurse Station — Tonight 24 rooms monitored

54

sleep score

Room 214

Alert

Breathing irregular · heart rate elevated

63

sleep score

Room 207

Watch

3 wake events · score down 18%

—

sleep score

Room 122

Check

No presence detected since 02:10

88

sleep score

Room 318

OK

Resting normally · steady breathing

80

sleep score

Room 305

OK

Resting normally · steady breathing

Caregiver dashboard

Nurse-station triage: overnight timelines, sleep scores & prioritized alerts across the wing

alerts + timelines

Cloud processing

Correlation engine

Tags each wake event with its likely environmental cause

Postgres

Per-resident history & baselines

ingest

MQTT broker (HiveMQ)

Receives per-minute JSON published by every node

Wi-Fi · MQTT

× N rooms

Sensor node

ESP32 Feather V2 · USB-C powered

mmWave radar

sleep · breathing · heart rate

BME680

temp · humidity · air

Microphone

noise level (dB)

Photoresistor

ambient light

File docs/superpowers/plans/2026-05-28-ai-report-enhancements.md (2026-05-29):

# AI Report Enhancements Implementation Plan

> **For agentic workers:** REQUIRED SUB-SKILL: Use superpowers:subagent-driven-development (recommended) or superpowers:executing-plans to implement this plan task-by-task. Steps use checkbox (`- [ ]`) syntax for tracking.

**Goal:** Upgrade the per-night LLM report with rigorous wake events (citations + confidence), a new sleep-health commentary paragraph, a richer prompt (15-column CSV + stats block + Sonnet 4.6), and a CLI script that regenerates any past night against the new pipeline.

**Architecture:** Extract the report-building pipeline from `lib/mqtt.ts` into `lib/sleepReport.ts` so the MQTT session-close path and a new `scripts/regenerate-report.ts` CLI share one code path. `lib/claude.ts` system prompt grows to ~80 lines, accepts a session-stats string alongside the CSV, and emits two new fields. Schema gains one nullable column; the rest is JSONB-shape-compatible.

**Tech Stack:** Next.js 16 (App Router), Postgres via `pg`, Anthropic SDK (`@anthropic-ai/sdk`), TypeScript, Tailwind v4. CLI uses `tsx` to run TS directly.

**Reference spec:** [docs/superpowers/specs/2026-05-28-ai-report-enhancements-design.md](../specs/2026-05-28-ai-report-enhancements-design.md)

**Working directory for all commands:** `/Users/yousefh/Desktop/Classes/EE284A/project/web`

**Note on TDD:** The `web/` package has no test framework configured (consistent with the prior dashboard plan). Each task ends with a manual verification step (build, lint, or running the regenerate script end-to-end).

---

## File Map

| File | Status | Responsibility |
|---|---|---|
| `lib/schema.ts` | Modify | Add `ALTER TABLE reports ADD COLUMN IF NOT EXISTS sleep_health TEXT;` |
| `lib/types.ts` | Modify | Add `WakeEvent` type with optional `triggers` + `confidence`; add `sleep_health?` to `SleepReport` |
| `lib/claude.ts` | Rewrite (in place) | New system prompt; `generateSleepReport(stats, csv)` signature; bump model + max_tokens |
| `lib/sleepReport.ts` | Create | Extracted pipeline: query telemetry → build stats + CSV → call LLM → persist (insert or update) |
| `lib/mqtt.ts` | Modify | `closeSession` becomes a thin wrapper around `lib/sleepReport.ts` |
| `app/api/nights/[id]/route.ts` | Modify | Select `r.sleep_health` |
| `app/components/WakeEvents.tsx` | Modify | Render optional confidence pill + trigger chips |
| `app/components/SleepHealth.tsx` | Create | Render `sleep_health` paragraphs |
| `app/page.tsx` | Modify | Add `<SleepHealth>` to the layout; pass `sleep_health` from `detail` |
| `scripts/regenerate-report.ts` | Create | CLI: `npx tsx scripts/regenerate-report.ts <night_id>` |

---

## Task 1: Schema — add `sleep_health` column

**Files:**
- Modify: `lib/schema.ts`

- [ ] **Step 1: Add the ALTER statement**

Open `lib/schema.ts`. Inside the `SCHEMA_SQL` template literal, find the block of `ALTER TABLE telemetry ADD COLUMN IF NOT EXISTS …` lines (around lines 46-69). After the entire telemetry block (and after the `reports` table definition further down), add a new line **right after the `reports` CREATE TABLE block**:

```sql
ALTER TABLE reports ADD COLUMN IF NOT EXISTS sleep_health TEXT;
```

The full reports section should now look like:

```sql
CREATE TABLE IF NOT EXISTS reports (
  id              BIGSERIAL PRIMARY KEY,
  night_id        BIGINT NOT NULL REFERENCES nights(id) ON DELETE CASCADE,
  headline        TEXT NOT NULL,
  sleep_score     INT,
  stage_pct       JSONB,
  vitals          JSONB,
  wake_events     JSONB,
  recommendations JSONB,
  generated_at    TIMESTAMPTZ NOT NULL DEFAULT now()
);

ALTER TABLE reports ADD COLUMN IF NOT EXISTS sleep_health TEXT;

CREATE INDEX IF NOT EXISTS reports_night_idx ON reports (night_id);
```

- [ ] **Step 2: Verify build**

Run: `npm run build 2>&1 | tail -5`
Expected: clean compile.

- [ ] **Step 3: Apply the migration on dev**

The schema is applied at boot via `instrumentation.ts`. Restart the dev server (or run a one-shot script) to ensure the ALTER runs. If a dev server is already up, kill it and restart it. On boot you should see `[migrate] schema applied` in the log (or no error from migrate).

If you can run a one-off query, verify:
```
psql ... -c "\d reports"
```
Expected: `sleep_health | text` column present.

- [ ] **Step 4: Commit**

```bash
git add lib/schema.ts
git commit -m "AI report: add reports.sleep_health column"
```

---

## Task 2: Types — extend `WakeEvent` and `SleepReport`

**Files:**
- Modify: `lib/types.ts`

- [ ] **Step 1: Replace the `SleepReport` block**

Open `lib/types.ts`. At the bottom of the file, find:

```ts
export type SleepReport = {
  headline: string;
  sleep_score: number;
  stage_pct: { awake: number; light: number; deep: number };
  vitals: { avg_breathing: number; avg_heart_rate: number };
  wake_events: { ts: string; likely_cause: string }[];
  recommendations: string[];
};
```

Replace it with:

```ts
export type WakeEvent = {
  ts: string;
  likely_cause: string;
  triggers?: string[];
  confidence?: "low" | "medium" | "high";
};

export type SleepReport = {
  headline: string;
  sleep_score: number;
  stage_pct: { awake: number; light: number; deep: number };
  vitals: { avg_breathing: number; avg_heart_rate: number };
  wake_events: WakeEvent[];
  recommendations: string[];
  sleep_health?: string;
};
```

- [ ] **Step 2: Verify TypeScript compiles**

Run: `npx tsc --noEmit 2>&1 | tail -5`
Expected: no errors. The existing consumers in `app/page.tsx`, `app/components/WakeEvents.tsx`, and `lib/mqtt.ts` only read fields that already exist on the new types, so no callsite changes are needed yet.

- [ ] **Step 3: Commit**

```bash
git add lib/types.ts
git commit -m "AI report: extend WakeEvent and SleepReport types"
```

---

## Task 3: Rewrite `lib/claude.ts` — new system prompt, stats parameter, Sonnet 4.6

**Files:**
- Modify (rewrite): `lib/claude.ts`

- [ ] **Step 1: Replace the entire file contents**

Open `lib/claude.ts`. Replace the entire file with:

```ts
import Anthropic from "@anthropic-ai/sdk";
import type { SleepReport } from "./types";

const client = new Anthropic({ apiKey: process.env.ANTHROPIC_API_KEY });
const MODEL = process.env.ANTHROPIC_MODEL ?? "claude-sonnet-4-6";

const SYSTEM_PROMPT = `You are a sleep coach analyzing one night of contactless mmWave radar data.

You receive: (1) a session-summary stats block and (2) a per-minute CSV of
telemetry. Your job is interpretation, not arithmetic — the numerical
summaries are already computed; cite them, don't recompute them.

Output ONLY a single JSON object with this exact shape (no prose outside it):

{
  "headline": "one short sentence summarizing the night",
  "sleep_score": <0-100 integer, your overall judgement>,
  "stage_pct": { "awake": <%>, "light": <%>, "deep": <%> },
  "vitals": { "avg_breathing": <bpm>, "avg_heart_rate": <bpm> },
  "wake_events": [
    {
      "ts": "H:MM AM/PM",
      "likely_cause": "one short sentence",
      "triggers": ["sound 62 dB", "HR 58→71 bpm", "state 1→2 for 4 min"],
      "confidence": "low" | "medium" | "high"
    }
  ],
  "recommendations": ["one specific suggestion for tonight"],
  "sleep_health": "1-3 short paragraphs of educational commentary"
}

CSV columns (one row per minute, local time):
  minute, sleep_state, breathing, hr, temp_c, humidity, pressure_hpa,
  gas_ohm, db_spl, light_raw, body_move_large, body_move_small,
  turnover, apnea_events, hr_instant

sleep_state values: 0=deep, 1=light, 2=awake, 3=out of bed
Movement fields are percentages of the minute spent moving.

=== Wake event rules ===

A wake event is a moment during the session when the radar or the vitals
suggest you came out of sleep, briefly or for longer.

Each event MUST include at least one entry in "triggers" — a short data
citation drawn from the CSV. Format each trigger as "channel value" or
"channel delta", e.g. "sound 62 dB", "HR 58→71 bpm", "state 1→2 for 4 min",
"temp drop 1.5°C", "movement 80% for 2 min".

Assign "confidence":
  - "high"   when ≥2 independent channels agree (sound spike AND HR jump,
             or state flip AND movement burst).
  - "medium" when one strong unambiguous channel (HR jumped ≥15 bpm but
             nothing else; or state flipped to awake for ≥3 minutes).
  - "low"    when only a weak signal (≤10 bpm HR dip, no other corroboration).

Do not invent wake events for periods where state stayed in light or deep
sleep AND no other channel showed an anomaly. Better to return an empty
wake_events array than to fabricate.

Use the wall-clock times from the CSV directly (they are already local).

=== Sleep health rules ===

The "sleep_health" field holds 1-3 short paragraphs of educational
commentary about this night, distinct from "recommendations".

  - "recommendations" = tactical things to do tonight ("dim lights earlier",
    "drop the thermostat 2°F").
  - "sleep_health" = what the data means, what the patterns suggest, how
    this night compares to typical adult sleep architecture, what's worth
    paying attention to over time.

Tone: calm, observational, educational. The voice of a thoughtful clinician,
not a wellness coach. No emoji, no exclamation marks. Cite specific numbers
from the stats block or CSV when making claims (e.g. "your 0 minutes of
deep sleep is unusual — most adults log 60-110 minutes per night").

Do not duplicate the tactical content of "recommendations" inside
"sleep_health".

=== General tone ===

Calm, concise, friendly but not effusive. No emoji. No prose outside the
JSON object. Do not pad. If a section has nothing to say, return an empty
array or a brief, honest sentence.`;

export async function generateSleepReport(stats: string, csvData: string): Promise<SleepReport> {
  const resp = await client.messages.create({
    model: MODEL,
    max_tokens: 2048,
    system: [
      { type: "text", text: SYSTEM_PROMPT, cache_control: { type: "ephemeral" } },
    ],
    messages: [
      {
        role: "user",
        content: `${stats}\n\nPer-minute telemetry:\n${csvData}\n\nGenerate the JSON report.`,
      },
    ],
  });
  const text = resp.content
    .filter((b) => b.type === "text")
    .map((b) => (b as { type: "text"; text: string }).text)
    .join("");
  const match = text.match(/\{[\s\S]*\}/);
  if (!match) throw new Error("No JSON in Claude response");
  return JSON.parse(match[0]) as SleepReport;
}
```

Note the signature is now `generateSleepReport(stats, csvData)` — the existing caller in `mqtt.ts` passes only `csv`, so this will break the build until Task 4/5 fix it.

- [ ] **Step 2: Verify TypeScript (build expected to fail)**

Run: `npx tsc --noEmit 2>&1 | tail -10`
Expected: an error in `lib/mqtt.ts` line ~98 about `generateSleepReport` expected 2 args, got 1. This is intentional — fixed in Task 5.

- [ ] **Step 3: Commit (intentionally broken — will be fixed in Task 5)**

```bash
git add lib/claude.ts
git commit -m "AI report: rewrite system prompt; add stats parameter; switch to Sonnet 4.6"
```

---

## Task 4: Create `lib/sleepReport.ts` — extracted pipeline

**Files:**
- Create: `lib/sleepReport.ts`

- [ ] **Step 1: Create the file**

Create `lib/sleepReport.ts`:

```ts
import { pool } from "./db";
import { generateSleepReport } from "./claude";

// Format a Date as local America/Los_Angeles "YYYY-MM-DD HH:MM" (24-hour).
function fmtMinute(d: Date): string {
  const p = new Intl.DateTimeFormat("en-CA", {
    timeZone: "America/Los_Angeles",
    year: "numeric", month: "2-digit", day: "2-digit",
    hour: "2-digit", minute: "2-digit", hour12: false,
  }).formatToParts(d);
  const get = (t: string) => p.find((x) => x.type === t)!.value;
  return `${get("year")}-${get("month")}-${get("day")} ${get("hour")}:${get("minute")}`;
}

// Format a Date as a local clock "H:MM AM/PM".
function fmtClock(d: Date): string {
  return d.toLocaleTimeString("en-US", {
    timeZone: "America/Los_Angeles",
    hour: "numeric", minute: "2-digit", hour12: true,
  });
}

function fmtHM(min: number): string {
  const h = Math.floor(min / 60);
  const m = Math.round(min % 60);
  return h > 0 ? `${h}h ${m}m` : `${m}m`;
}

type MinuteRow = {
  minute: Date;
  sleep_state: number | null;
  breathing: number | null;
  hr: number | null;
  temp_c: number | null;
  humidity: number | null;
  pressure_hpa: number | null;
  gas_ohm: number | null;
  db_spl: number | null;
  light_raw: number | null;
  body_move_large: number | null;
  body_move_small: number | null;
  turnover: number | null;
  apnea_events: number | null;
  hr_instant: number | null;
};

// Fetch per-minute aggregated telemetry for a session window (15 columns the LLM uses).
async function fetchMinuteRows(device: string, startedAt: Date, endedAt: Date): Promise<MinuteRow[]> {
  const { rows } = await pool.query<MinuteRow>(
    `SELECT date_trunc('minute', ts) AS minute,
            avg(sleep_state)::int AS sleep_state,
            avg(breathing)::int AS breathing,
            avg(heart_rate)::int AS hr,
            avg(temp_c) AS temp_c,
            avg(humidity) AS humidity,
            avg(pressure_hpa) AS pressure_hpa,
            avg(gas_ohm)::int AS gas_ohm,
            avg(db_spl) AS db_spl,
            avg(light_raw)::int AS light_raw,
            avg(body_move_large)::int AS body_move_large,
            avg(body_move_small)::int AS body_move_small,
            avg(turnover)::int AS turnover,
            avg(apnea_events)::int AS apnea_events,
            avg(hr_instant)::int AS hr_instant
     FROM telemetry WHERE device = $1 AND ts BETWEEN $2 AND $3
     GROUP BY minute ORDER BY minute`,
    [device, startedAt, endedAt]
  );
  return rows;
}

// Build the CSV body string (15 columns, header + one row per minute).
function buildCsv(rows: MinuteRow[]): string {
  const header =
    "minute,sleep_state,breathing,hr,temp_c,humidity,pressure_hpa,gas_ohm,db_spl,light_raw,body_move_large,body_move_small,turnover,apnea_events,hr_instant";
  const lines = rows.map((r) => {
    const c = [
      fmtMinute(r.minute),
      r.sleep_state,
      r.breathing,
      r.hr,
      r.temp_c !== null ? Number(r.temp_c).toFixed(1) : "",
      r.humidity !== null ? Number(r.humidity).toFixed(1) : "",
      r.pressure_hpa !== null ? Number(r.pressure_hpa).toFixed(1) : "",
      r.gas_ohm,
      r.db_spl !== null ? Number(r.db_spl).toFixed(1) : "",
      r.light_raw,
      r.body_move_large,
      r.body_move_small,
      r.turnover,
      r.apnea_events,
      r.hr_instant,
    ];
    return c.map((v) => (v === null || v === undefined ? "" : String(v))).join(",");
  });
  return [header, ...lines].join("\n");
}

// Build the session-summary stats block prepended to the user message.
async function buildStats(device: string, startedAt: Date, endedAt: Date): Promise<string> {
  const durationSec = Math.floor((endedAt.getTime() - startedAt.getTime()) / 1000);
  const { rows: agg } = await pool.query<{
    light_max: number | null;
    deep_max: number | null;
    wake_max: number | null;
    turnover_max: number | null;
    apnea_max: number | null;
    quality_max: number | null;
  }>(
    `SELECT max(light_sleep_dur)::int AS light_max,
            max(deep_sleep_dur)::int AS deep_max,
            max(wake_dur)::int AS wake_max,
            max(turnover_total)::int AS turnover_max,
            max(apnea_events)::int AS apnea_max,
            max(sleep_quality)::int AS quality_max
     FROM telemetry WHERE device = $1 AND ts BETWEEN $2 AND $3`,
    [device, startedAt, endedAt]
  );
  const a = agg[0] ?? { light_max: null, deep_max: null, wake_max: null, turnover_max: null, apnea_max: null, quality_max: null };
  const line = (label: string, val: string | number | null) =>
    val === null || val === undefined ? `${label}: unavailable` : `${label}: ${val}`;
  return [
    `Session: ${fmtHM(Math.round(durationSec / 60))}`,
    `Asleep at: ${fmtClock(startedAt)}, awake at: ${fmtClock(endedAt)}`,
    line("Light sleep (sensor)", a.light_max !== null ? `${a.light_max} min` : null),
    line("Deep sleep (sensor)", a.deep_max !== null ? `${a.deep_max} min` : null),
    line("Awake in bed", a.wake_max !== null ? `${a.wake_max} min` : null),
    line("Turnover", a.turnover_max),
    line("Apnea events", a.apnea_max),
    line("Sensor sleep quality", a.quality_max !== null ? `${a.quality_max}/100` : null),
  ].join("\n");
}

// Build and persist (insert or update) the LLM report for a given night.
// Used by both the MQTT session-close path and the regenerate-report CLI.
export async function buildAndStoreReport(
  device: string,
  nightId: number,
  startedAt: Date,
  endedAt: Date,
): Promise<{ headline: string; sleep_score: number }> {
  const rows = await fetchMinuteRows(device, startedAt, endedAt);
  const csv = buildCsv(rows);
  const stats = await buildStats(device, startedAt, endedAt);

  const report = await generateSleepReport(stats, csv);

  await pool.query(
    `INSERT INTO reports (night_id, headline, sleep_score, stage_pct, vitals, wake_events, recommendations, sleep_health)
     VALUES ($1, $2, $3, $4, $5, $6, $7, $8)
     ON CONFLICT (night_id) DO UPDATE SET
       headline = EXCLUDED.headline,
       sleep_score = EXCLUDED.sleep_score,
       stage_pct = EXCLUDED.stage_pct,
       vitals = EXCLUDED.vitals,
       wake_events = EXCLUDED.wake_events,
       recommendations = EXCLUDED.recommendations,
       sleep_health = EXCLUDED.sleep_health,
       generated_at = now()`,
    [
      nightId,
      report.headline,
      report.sleep_score,
      report.stage_pct,
      report.vitals,
      JSON.stringify(report.wake_events),
      JSON.stringify(report.recommendations),
      report.sleep_health ?? null,
    ],
  );
  await pool.query(`UPDATE nights SET sleep_score = $1 WHERE id = $2`,
    [report.sleep_score, nightId]);

  return { headline: report.headline, sleep_score: report.sleep_score };
}
```

The `ON CONFLICT (night_id) DO UPDATE` requires a unique constraint on `reports.night_id`. The current schema has `reports_night_idx` as a non-unique index, so this ON CONFLICT won't fire. Two options to handle: either delete-then-insert, or add a unique constraint.

- [ ] **Step 2: Add a unique constraint on `reports.night_id`**

Modify `lib/schema.ts` again. After the existing `CREATE INDEX IF NOT EXISTS reports_night_idx ON reports (night_id);` line, add:

```sql
CREATE UNIQUE INDEX IF NOT EXISTS reports_night_unique_idx ON reports (night_id);
```

This is safe to add: any existing duplicate `night_id` rows would cause the index creation to fail. If that happens, the operator can manually deduplicate; current behavior already only inserts one report per night, so duplicates shouldn't exist.

- [ ] **Step 3: Verify build (still broken by Task 3 — that's expected)**

Run: `npm run build 2>&1 | tail -10`
Expected: the same `generateSleepReport` arity error from Task 3 in `lib/mqtt.ts`. Will be fixed in Task 5.

- [ ] **Step 4: Commit**

```bash
git add lib/sleepReport.ts lib/schema.ts
git commit -m "AI report: extract report-building pipeline into lib/sleepReport.ts"
```

---

## Task 5: Refactor `lib/mqtt.ts` `closeSession` to delegate to `sleepReport.ts`

**Files:**
- Modify: `lib/mqtt.ts`

- [ ] **Step 1: Replace imports**

In `lib/mqtt.ts`, find the imports at the top:

```ts
import { generateSleepReport } from "./claude";
```

Replace with:

```ts
import { buildAndStoreReport } from "./sleepReport";
```

- [ ] **Step 2: Simplify `closeSession`**

Find the entire `closeSession` function (currently lines 48-110 in the file). Replace its body so it inserts the `nights` row and delegates report building:

```ts
async function closeSession(dev: string, endedAt: Date) {
  const s = getSession(dev);
  if (!s.startedAt) return;
  const startedAt = s.startedAt;
  const durationSec = Math.floor((endedAt.getTime() - startedAt.getTime()) / 1000);
  s.startedAt = null;
  s.consecutiveInBed = 0;
  s.consecutiveOutOfBed = 0;
  s.consecutiveAwake = 0;

  if (durationSec < MIN_VALID_SESSION_HOURS * 3600) return;

  const { rows: nightRows } = await pool.query<{ id: number }>(
    `INSERT INTO nights (device, started_at, ended_at, duration_sec)
     VALUES ($1, $2, $3, $4) RETURNING id`,
    [dev, startedAt, endedAt, durationSec]
  );
  const nightId = nightRows[0].id;

  try {
    await buildAndStoreReport(dev, nightId, startedAt, endedAt);
  } catch (err) {
    console.error("[mqtt] LLM report failed for night", nightId, err);
  }
}
```

- [ ] **Step 3: Verify build**

Run: `npm run build 2>&1 | tail -10`
Expected: clean compile. The arity error from Task 3 is now resolved.

- [ ] **Step 4: Verify lint**

Run: `npm run lint 2>&1 | tail -10`
Expected: only pre-existing warnings. No new errors.

- [ ] **Step 5: Commit**

```bash
git add lib/mqtt.ts
git commit -m "AI report: simplify closeSession to delegate to buildAndStoreReport"
```

---

## Task 6: API route selects `sleep_health`

**Files:**
- Modify: `app/api/nights/[id]/route.ts`

- [ ] **Step 1: Add `r.sleep_health` to the SELECT**

Open `app/api/nights/[id]/route.ts`. Find the night row query (around lines 8-12). Update the SELECT to include `r.sleep_health`:

```ts
const { rows: nightRows } = await pool.query(
  `SELECT n.*, r.headline, r.sleep_score AS report_score, r.stage_pct, r.vitals,
          r.wake_events, r.recommendations, r.sleep_health
   FROM nights n LEFT JOIN reports r ON r.night_id = n.id
   WHERE n.id = $1`, [id]);
```

- [ ] **Step 2: Verify build**

Run: `npm run build 2>&1 | tail -5`
Expected: clean compile.

- [ ] **Step 3: Commit**

```bash
git add app/api/nights/[id]/route.ts
git commit -m "AI report: return sleep_health from /api/nights/:id"
```

---

## Task 7: `WakeEvents` — confidence pill + trigger chips

**Files:**
- Modify: `app/components/WakeEvents.tsx`

- [ ] **Step 1: Add the optional fields to the local `WakeEvent` type and update render**

Open `app/components/WakeEvents.tsx`. Replace the local `WakeEvent` type definition at the top:

```ts
type WakeEvent = {
  ts: string;
  likely_cause: string;
  triggers?: string[];
  confidence?: "low" | "medium" | "high";
};
```

Then, inside the `events.map` JSX block, replace the current `<li>` with this richer version:

```tsx
{events.map((e, i) => (
  <li key={i} className="space-y-1">
    <div className="flex items-baseline gap-4">
      <span className="font-mono text-[13px] text-ink-muted">
        {fmtWakeTs(e.ts, nightStartedAt, nightEndedAt)}
      </span>
      <span className="flex-1">{e.likely_cause}</span>
      {e.confidence && (
        <span
          className="rounded-full bg-copper-soft px-2 py-0.5 text-[10px] font-medium uppercase tracking-[0.08em] text-copper"
        >
          {e.confidence === "medium" ? "med" : e.confidence}
        </span>
      )}
    </div>
    {e.triggers && e.triggers.length > 0 && (
      <div className="flex flex-wrap gap-1.5 pl-[5.5rem]">
        {e.triggers.map((t, j) => (
          <span
            key={j}
            className="rounded border border-rule px-1.5 py-0.5 font-mono text-[11px] text-ink-muted"
          >
            {t}
          </span>
        ))}
      </div>
    )}
  </li>
))}
```

The `pl-[5.5rem]` aligns the trigger chips under the cause text, past the timestamp column. Adjust if your design eye disagrees.

- [ ] **Step 2: Verify TypeScript**

Run: `npx tsc --noEmit 2>&1 | tail -5`
Expected: no errors. The wider `WakeEvent` type in `lib/types.ts` (Task 2) is compatible with the local definition.

- [ ] **Step 3: Commit**

```bash
git add app/components/WakeEvents.tsx
git commit -m "AI report: render confidence pill and trigger chips on wake events"
```

---

## Task 8: New `SleepHealth` component

**Files:**
- Create: `app/components/SleepHealth.tsx`

- [ ] **Step 1: Create the component**

Create `app/components/SleepHealth.tsx`:

```tsx
type Props = { text: string | null | undefined };

export function SleepHealth({ text }: Props) {
  if (!text || text.trim().length === 0) return null;
  // Split on blank lines for paragraphs.
  const paragraphs = text.split(/\n\s*\n/).map((p) => p.trim()).filter(Boolean);
  return (
    <section className="space-y-3">
      <h2 className="text-[11px] font-medium uppercase tracking-[0.08em] text-ink-muted">Sleep health</h2>
      <div className="space-y-3 text-[15px] leading-relaxed text-ink">
        {paragraphs.map((p, i) => (
          <p key={i}>{p}</p>
        ))}
      </div>
    </section>
  );
}
```

- [ ] **Step 2: Verify TypeScript**

Run: `npx tsc --noEmit 2>&1 | tail -5`
Expected: clean.

- [ ] **Step 3: Commit**

```bash
git add app/components/SleepHealth.tsx
git commit -m "AI report: add SleepHealth component"
```

---

## Task 9: Wire `SleepHealth` into the page

**Files:**
- Modify: `app/page.tsx`

- [ ] **Step 1: Add the type field and import**

In `app/page.tsx`, at the top imports block, add `SleepHealth` import:

```ts
import { SleepHealth } from "./components/SleepHealth";
```

Find the `NightDetail` type's `night` shape and add `sleep_health` to it:

```ts
type NightDetail = {
  night: {
    id: number;
    device: string;
    started_at: string;
    ended_at: string;
    duration_sec: number;
    sleep_score: number | null;
    headline: string | null;
    report_score: number | null;
    stage_pct: StagePct | null;
    vitals: Vitals | null;
    wake_events: WakeEvent[] | null;
    recommendations: string[] | null;
    sleep_health: string | null;
  };
  // eslint-disable-next-line @typescript-eslint/no-explicit-any
  telemetry: any[];
};
```

- [ ] **Step 2: Render `SleepHealth` in the two-column block**

Find the existing two-column block (currently `WakeEvents` + `Recommendations` in a `grid sm:grid-cols-2`). Restructure to a three-section layout: wake events on the left, Tonight + Sleep health stacked on the right.

Replace:

```tsx
{!slot.inProgress && (
  <div className="grid gap-10 sm:grid-cols-2">
    <WakeEvents
      events={detail?.night.wake_events ?? null}
      nightStartedAt={detail?.night.started_at ?? null}
      nightEndedAt={detail?.night.ended_at ?? null}
    />
    <Recommendations items={detail?.night.recommendations ?? null} />
  </div>
)}
```

With:

```tsx
{!slot.inProgress && (
  <div className="grid gap-10 sm:grid-cols-2">
    <WakeEvents
      events={detail?.night.wake_events ?? null}
      nightStartedAt={detail?.night.started_at ?? null}
      nightEndedAt={detail?.night.ended_at ?? null}
    />
    <div className="space-y-8">
      <Recommendations items={detail?.night.recommendations ?? null} />
      <SleepHealth text={detail?.night.sleep_health ?? null} />
    </div>
  </div>
)}
```

- [ ] **Step 3: Verify build + lint**

Run: `npm run build 2>&1 | tail -10`
Expected: clean.

Run: `npm run lint 2>&1 | tail -10`
Expected: only pre-existing warnings.

- [ ] **Step 4: Commit**

```bash
git add app/page.tsx
git commit -m "AI report: render SleepHealth alongside Recommendations"
```

---

## Task 10: Regenerate CLI script

**Files:**
- Create: `scripts/regenerate-report.ts`

- [ ] **Step 1: Confirm `tsx` is available**

Run: `npx tsx --version 2>&1 | tail -2`
Expected: a version number printed (e.g. `tsx v4.x.x`). If it fails with "not found", install it as a dev dependency:

```bash
npm install --save-dev tsx
```

- [ ] **Step 2: Create the script**

Create `scripts/regenerate-report.ts`:

```ts
import { config } from "dotenv";
config({ path: ".env.local" });

import { pool } from "../lib/db";
import { buildAndStoreReport } from "../lib/sleepReport";

async function main() {
  const idArg = process.argv[2];
  if (!idArg) {
    console.error("usage: npx tsx scripts/regenerate-report.ts <night_id>");
    process.exit(1);
  }
  const nightId = Number(idArg);
  if (!Number.isInteger(nightId) || nightId <= 0) {
    console.error(`invalid night id: ${idArg}`);
    process.exit(1);
  }

  const { rows } = await pool.query<{
    device: string;
    started_at: string;
    ended_at: string;
  }>(
    `SELECT device, started_at, ended_at FROM nights WHERE id = $1`,
    [nightId],
  );
  if (rows.length === 0) {
    console.error(`night not found: ${nightId}`);
    process.exit(1);
  }

  const { device, started_at, ended_at } = rows[0];
  console.log(`Regenerating report for night ${nightId} (device=${device}) ...`);

  const result = await buildAndStoreReport(
    device,
    nightId,
    new Date(started_at),
    new Date(ended_at),
  );

  console.log(`Done. score=${result.sleep_score}`);
  console.log(`headline: ${result.headline}`);
  await pool.end();
}

main().catch((err) => {
  console.error(err);
  process.exit(1);
});
```

Note `dotenv` may already be a dependency via Next.js, but the script runs outside Next so it needs to load `.env.local` explicitly. If `dotenv` isn't installed, install it: `npm install --save-dev dotenv`.

- [ ] **Step 3: Install missing deps if any**

```bash
npm ls dotenv tsx 2>&1 | tail -10
```

Install whichever are missing:
```bash
npm install --save-dev tsx dotenv
```

- [ ] **Step 4: Verify it parses**

Run: `npx tsc --noEmit 2>&1 | tail -5`
Expected: clean.

- [ ] **Step 5: Commit**

```bash
git add scripts/regenerate-report.ts package.json package-lock.json
git commit -m "AI report: add scripts/regenerate-report.ts CLI"
```

---

## Task 11: End-to-end smoke test — regenerate last night

**Files:** none (verification only).

- [ ] **Step 1: Identify the most recent night id**

Hit the running dev server's `/api/nights` endpoint (must be logged in in the browser), or use psql if available:

```
SELECT id, started_at, ended_at FROM nights ORDER BY started_at DESC LIMIT 1;
```

Note the returned `id`.

- [ ] **Step 2: Restart dev server so schema migration applies**

If the dev server is currently running, kill it and restart it (`npm run dev`). On boot the `instrumentation.ts` migration runs and adds the `sleep_health` column and unique index.

Confirm in the dev server log there are no migration errors. If the `CREATE UNIQUE INDEX` fails due to duplicate `night_id` rows in `reports`, manually deduplicate first:

```
DELETE FROM reports a USING reports b WHERE a.id < b.id AND a.night_id = b.night_id;
```

Then restart.

- [ ] **Step 3: Run the regenerate script for that night**

```bash
npx tsx scripts/regenerate-report.ts <night_id>
```

Expected: prints "Regenerating report for night ... (device=sleep01)" then "Done. score=N" and "headline: ...". Total runtime ~10-30s (one Sonnet 4.6 call).

If you see "no JSON in Claude response" or a JSON parse error, the LLM didn't follow the schema. Re-run; if it persists, inspect the raw response by temporarily logging `text` in `lib/claude.ts` before the JSON match.

- [ ] **Step 4: Verify in the dashboard**

Open the dev server in browser. Navigate to that night (date picker or prev/next). Expect:
- The hero headline reflects the new prompt's voice.
- Wake events (if any) now show a confidence pill on the right and trigger chips beneath each cause.
- A new "Sleep health" section appears beside (or below) "Tonight," with 1-3 paragraphs.
- No console errors.

- [ ] **Step 5: Smoke-test fallback for a legacy night**

Pick an older night that hasn't been regenerated. Open it in the dashboard. Expect:
- Wake events render as today (no confidence pill, no trigger chips).
- No "Sleep health" section appears.
- No console errors.

- [ ] **Step 6: Final commit if any fixes were needed**

If you had to tweak anything during the smoke test (e.g. dedupe rows, fix a typo), commit it:

```bash
git commit -am "AI report: smoke-test fixes"
```

Otherwise skip.

---

## Self-review checklist (applied — do not re-run if reading)

- **Spec coverage:** schema/types/prompt/UI/regenerate script all mapped to tasks (1-10). Last-night regeneration mapped to Task 11. The split of `lib/sleepReport.ts` matches the spec's "Components and boundaries" section.
- **Placeholders:** every code block contains actual code. No "TBD" / "implement later" / "similar to Task N".
- **Type consistency:** `generateSleepReport(stats, csvData)` is the new signature used in Tasks 3 and 4; old single-arg call removed in Task 5. `WakeEvent` extended in Task 2; consumed in Task 7. `sleep_health` flows from DB (Task 1) → API (Task 6) → page (Task 9) → component (Task 8).
- **Risks called out in spec are addressed in plan:** the `ON CONFLICT (night_id) DO UPDATE` requirement led to a unique-index addition (Task 4 step 2) plus a dedupe escape hatch in the smoke test (Task 11 step 2).

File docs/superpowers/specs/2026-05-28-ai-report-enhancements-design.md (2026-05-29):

# AI Report Enhancements — Design Spec

**Date:** 2026-05-28
**Scope:** Improve the per-night LLM report generated by `lib/claude.ts`. Tighter wake events (cited evidence + confidence), new sleep-health commentary section, prompt that grounds claims in pre-computed stats. A one-shot script to regenerate any past night's report against the new prompt.

**Out of scope:** Chatbot, multi-night context/trends, phased narrative, vitals story, cross-channel observation lists, free-form "notable observations" field, UI regenerate button, batch backfill of all historical reports.

## Goal

Two complaints drive this work:

1. **Wake events are vague and sometimes hallucinated.** "Brief arousal with dropped breathing and heart rate" reads like the LLM is making things up — there is no citation, no confidence, no way to tell which channel triggered it, no requirement that the radar agreed.
2. **Recommendations are thin.** A handful of tactical bullets like "keep the room cooler." No room for the LLM to explain what your sleep architecture actually looked like or what to watch for over time.

Both can be fixed by changing the system prompt and broadening the report schema. The LLM keeps its current job (interpretation, not arithmetic) but is given more raw material to reference and a tighter rubric for how to write.

## Schema

Two changes to the `reports.JSONB` payload and the `SleepReport` type in `lib/types.ts`:

### Wake events (each item)

```ts
type WakeEvent = {
  ts: string;                       // local HH:MM, wall-clock time (already in PST)
  likely_cause: string;             // one sentence summary
  triggers?: string[];              // NEW: cited data points, 1-4 items
  confidence?: "low" | "medium" | "high";  // NEW
};
```

`triggers` and `confidence` are optional so legacy reports (no new fields) render gracefully without migration.

Examples of `triggers` items:
- `"sound 62 dB"`
- `"HR 58→71 bpm"`
- `"state 1→2 for 4 min"`
- `"temp drop 1.5°C"`

### New top-level field

```ts
type SleepReport = {
  // ...existing fields unchanged...
  sleep_health?: string;            // NEW: 1-3 short paragraphs
};
```

`sleep_health` holds an educational paragraph (or two or three) covering broad observations about the night's sleep architecture and what the patterns suggest. Calm, observational voice. Not coachy. Distinct from `recommendations`, which stays the same shape and remains tactical.

### Database

`lib/schema.ts` gains:

```sql
ALTER TABLE reports ADD COLUMN IF NOT EXISTS sleep_health TEXT;
```

The wake-event upgrade needs no schema change — `wake_events` is already JSONB.

## Prompt

`lib/claude.ts` system prompt grows from ~14 lines to ~50 lines. The shape of the call (system + user message + parse JSON from response) stays the same. Three substantive changes:

### 1. Pre-computed stats join the user message

Today the user message contains only the per-minute CSV. After this change, it includes a stats block at the top followed by the CSV:

```
Session: 4h 41m
Asleep at: 12:16 AM, awake at: 4:58 AM
Light sleep (sensor): 237 min
Deep sleep (sensor): 0 min
Awake in bed: 8 min
Turnover: 17
Apnea events: 0
Sensor sleep quality: 43/100

Per-minute telemetry (one row per minute, local PST):
minute,state,breathing,hr,temp_c,humidity,gas_ohm,db_spl,light
2026-05-28 00:16,1,14,62,21.3,42.1,30421,38.2,12
...
```

The stats are computed in the same place that already aggregates them (`closeSession` in `lib/mqtt.ts`, or its extracted helper — see "Implementation"). The LLM cites these numbers in its narrative rather than recomputing them.

### 2. Wake event rubric

New explicit rules in the system prompt:

- Each wake event MUST cite at least one entry in `triggers`. Triggers are short data citations drawn from the CSV (channel + value or delta).
- Assign `confidence`:
  - **high** when ≥2 independent channels agree (e.g. sound spike AND HR jump AND state flip).
  - **medium** when one strong, unambiguous channel (e.g. HR jumped 15+ bpm but nothing else).
  - **low** when only inferred from one weak signal (e.g. a 3 bpm HR dip with no other corroboration).
- Use wall-clock times from the CSV (already local PST after the timezone fix).
- Do not invent wake events for periods where the radar's `state` field never flipped out of light/deep sleep AND no other channel showed an anomaly.

### 3. Sleep health section

Add a `sleep_health` field to the JSON spec inside the system prompt with these requirements:

- 1-3 short paragraphs.
- Tone: calm, observational, educational. The voice of a thoughtful clinician, not a wellness coach. No emoji, no exclamation marks, no "you've got this!" energy. Matches the existing brand voice.
- Should cover: sleep architecture observations (deep/light/awake distribution), what the patterns suggest, context for the numbers (e.g. why a low deep-sleep ratio matters, what a normal range looks like), and any specific health-relevant observations from the data.
- Must cite specific numbers when making claims (e.g. "your 0 minutes of deep sleep is unusual — most adults log 60-110 minutes per night").
- Must NOT duplicate the tactical content of `recommendations`. `recommendations` says "do this tonight." `sleep_health` says "here's what the data means and what to watch for."

### Other prompt notes

- `max_tokens` bumps from 1024 → 2048 to fit the longer output.
- `MODEL` env default changes from `claude-haiku-4-5` to `claude-sonnet-4-6` for better narrative quality. Still overridable by `ANTHROPIC_MODEL` env var.

## UI

### Wake events — `app/components/WakeEvents.tsx`

Each event renders the existing `ts` + `likely_cause`, and additionally:

- A confidence pill on the right end of the first row, only if `confidence` is present. Three variants, using copper-soft tinting and uppercase eyebrow text styling: `low`, `med`, `high`. Visual weight matches the existing `in progress` pill in NightHeader.
- A row of trigger chips below the cause text, only if `triggers` is present and non-empty. Each chip is a small monospace pill with the trigger text. Subtle styling — `rule`-bordered, mono font, ink-muted color.

Legacy reports (no `confidence`, no `triggers`) render exactly as today.

### New component — `app/components/SleepHealth.tsx`

A simple component that renders the `sleep_health` paragraphs under a `Sleep health` uppercase eyebrow. Same typographic treatment as `Recommendations`. Returns `null` when the field is missing or empty.

### Layout — `app/page.tsx`

The existing two-column "Wake events / Recommendations" block becomes three rendered sections:

- Wake events (unchanged position)
- "Tonight" — the existing `Recommendations` component
- "Sleep health" — the new `SleepHealth` component

On desktop, sit them in a grid: wake events on the left, Tonight + Sleep health stacked on the right (or a 3-column grid — to be decided by visual judgement at implementation time). On mobile, stack vertically as today.

### Types — `lib/types.ts`

```ts
export type WakeEvent = {
  ts: string;
  likely_cause: string;
  triggers?: string[];
  confidence?: "low" | "medium" | "high";
};

export type SleepReport = {
  headline: string;
  sleep_score: number;
  stage_pct: { awake: number; light: number; deep: number };
  vitals: { avg_breathing: number; avg_heart_rate: number };
  wake_events: WakeEvent[];
  recommendations: string[];
  sleep_health?: string;
};
```

### API — `app/api/nights/[id]/route.ts`

The `SELECT` for the night row gains `r.sleep_health`. Everything else stays.

## Implementation

The telemetry-fetch + CSV-build + stats-build + LLM-call sequence currently lives inside `closeSession` in `lib/mqtt.ts`. Extract it into a shared helper so the new regenerate script and the existing session-close path call the same code:

- New file: `web/lib/sleepReport.ts`
- Exported function: `buildAndStoreReport(device: string, nightId: number, startedAt: Date, endedAt: Date): Promise<void>`
- Internals: runs the per-minute aggregation query, computes the stats block, builds the local-PST CSV, calls `generateSleepReport(stats, csv)` (signature gets a new `stats` parameter), `INSERT … ON CONFLICT (night_id) DO UPDATE` into `reports`, and updates `nights.sleep_score`.
- `closeSession` becomes a thin wrapper: insert the `nights` row, then call `buildAndStoreReport(...)`.

`generateSleepReport` gains a `stats` parameter (the rendered stats block string) that prepends the CSV in the user message.

## Regenerate script

New file: `web/scripts/regenerate-report.ts`.

Usage:

```
npx tsx scripts/regenerate-report.ts <night_id>
```

Behavior:

1. Loads `.env.local`.
2. Queries the `nights` row by id; errors out if not found.
3. Calls `buildAndStoreReport(device, id, started_at, ended_at)`.
4. Logs success with the new report's headline.

No UI surface; manual invocation only. Future "Regenerate" button in the UI is a follow-up and out of scope here.

## Migration

- Run `ALTER TABLE reports ADD COLUMN IF NOT EXISTS sleep_health TEXT;` via the existing schema-apply on next dev boot (already idempotent via `instrumentation.ts`).
- Legacy reports lack `sleep_health` and lack `triggers`/`confidence` on their wake events. The UI handles missing fields with `?.` and conditional rendering. No backfill is performed automatically — users regenerate specific nights via the script when they want the new format.

## Components and boundaries

- `lib/sleepReport.ts` (new) — pure report-building pipeline. One responsibility: given a (device, nightId, window), build the stats + CSV, call the LLM, and persist the report.
- `lib/claude.ts` — LLM call only. Signature changes to accept a `stats` block.
- `lib/mqtt.ts` — session detection only. Delegates report building to `sleepReport.ts`.
- `app/components/WakeEvents.tsx` — render wake events with the new optional fields.
- `app/components/SleepHealth.tsx` (new) — render the sleep-health paragraphs.
- `scripts/regenerate-report.ts` (new) — one-shot CLI entry point.

## Success criteria

- A regenerated last-night report has at least one wake event whose `triggers` array contains the data citation the LLM used to justify the event, and a `confidence` value.
- The same report includes a `sleep_health` field of 1-3 paragraphs that cites specific numbers from the night and reads in a calm, observational voice.
- The dashboard for that night renders confidence pills and trigger chips under each wake event, and a new "Sleep health" section.
- Legacy reports continue to render correctly with no errors and no new fields visible.
- `npx tsx scripts/regenerate-report.ts <id>` overwrites that night's report end-to-end without affecting other nights.
- Build and lint stay clean.

## Risks

- **Prompt cost / latency.** Sonnet 4.6 is more expensive than Haiku 4.5 and the stats block + larger output increases token use. Acceptable for the low-frequency one-per-night job, but worth noting if regeneration of many nights happens at once.
- **LLM still hallucinates.** The rubric reduces but does not eliminate the risk of made-up wake events. The confidence pill puts the calibration in the user's hands as a partial mitigation.
- **Schema drift.** Optional fields keep us safe from a hard migration, but the codebase now has two "shapes" of report in production. Acceptable for this iteration; consolidate later if it gets confusing.

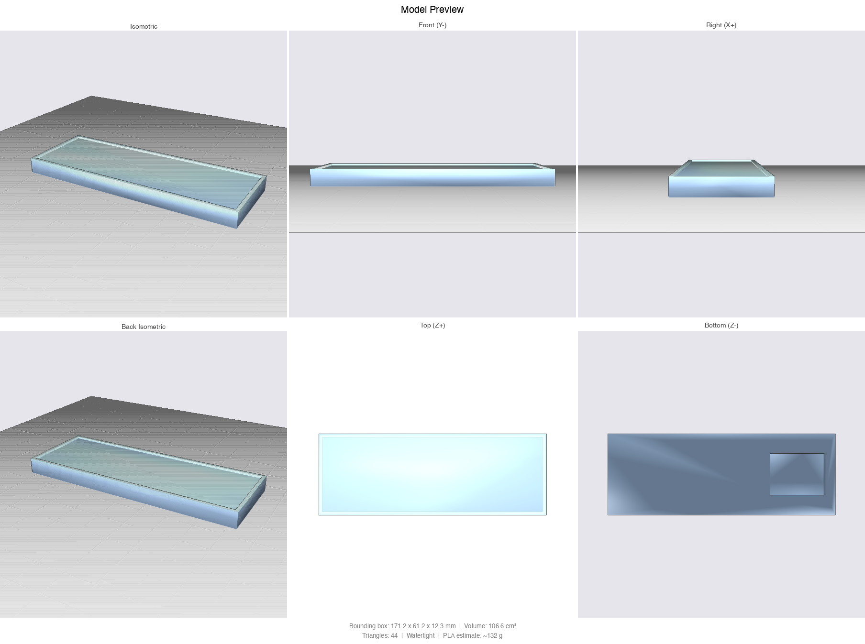
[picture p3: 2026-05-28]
cad/housing_phase1_preview.png

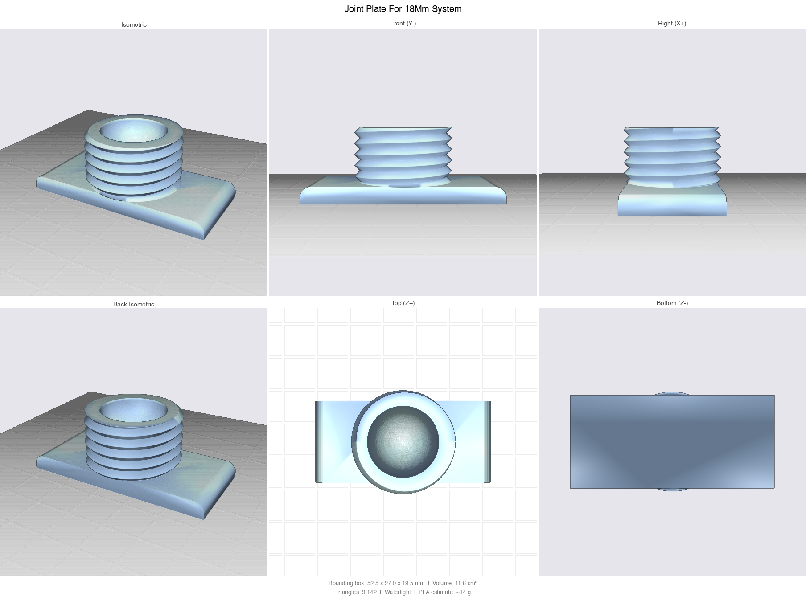
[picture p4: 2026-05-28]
cad/joint/Joint plate for 18mm system_preview.png

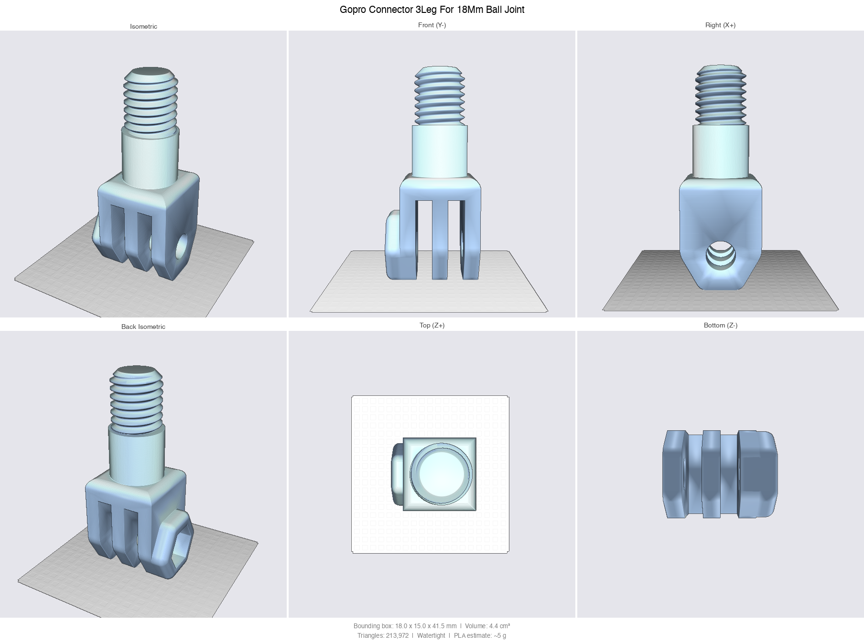
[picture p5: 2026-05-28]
cad/joint/GoPro connector 3leg for 18mm ball joint_preview.png

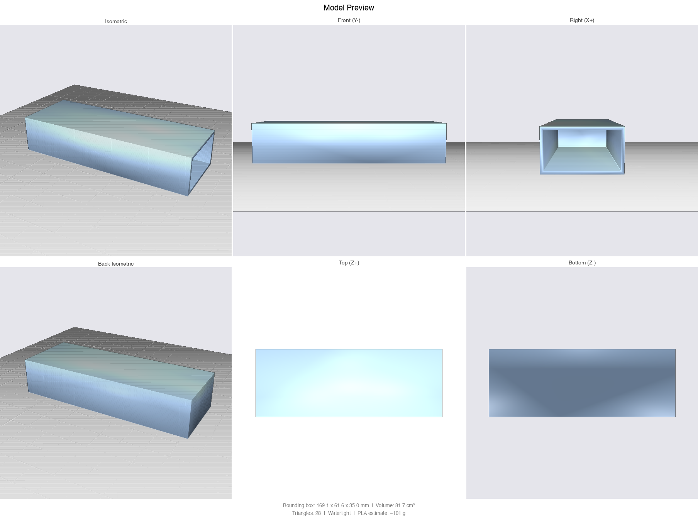
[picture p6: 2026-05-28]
cad/housing_phase2_preview.png

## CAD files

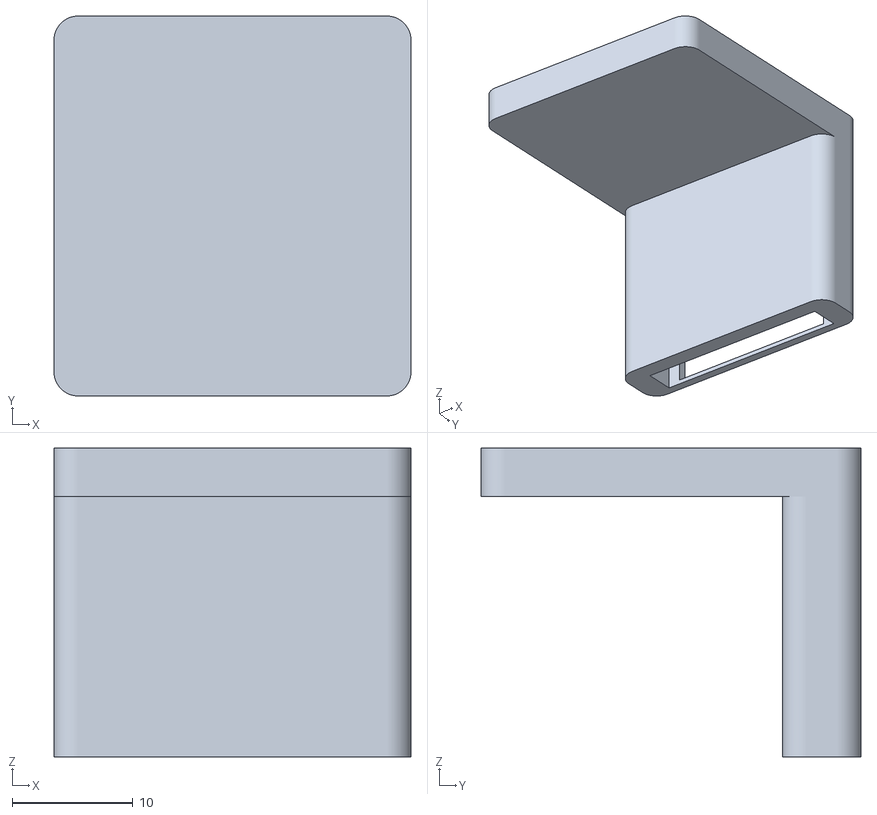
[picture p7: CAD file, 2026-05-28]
cad/c1001_holder.stl
29.6 x 31.5 x 25.6

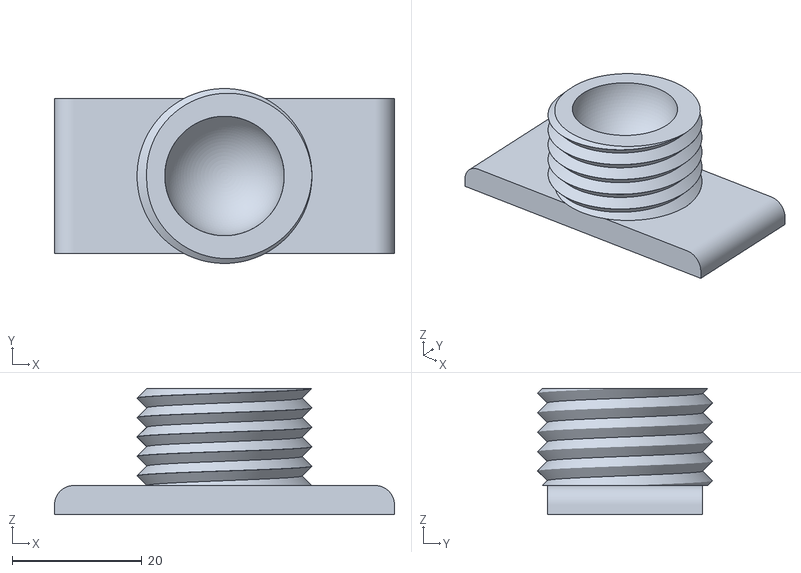
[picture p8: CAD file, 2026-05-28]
cad/joint/Joint plate for 18mm system.stl
52.5 x 27.0 x 19.5

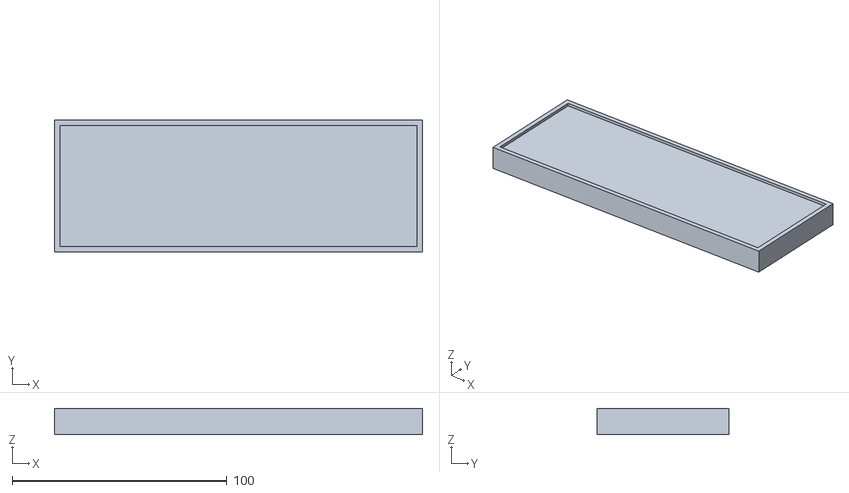
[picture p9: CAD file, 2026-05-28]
cad/housing_phase1.stl
171.2 x 61.2 x 12.3

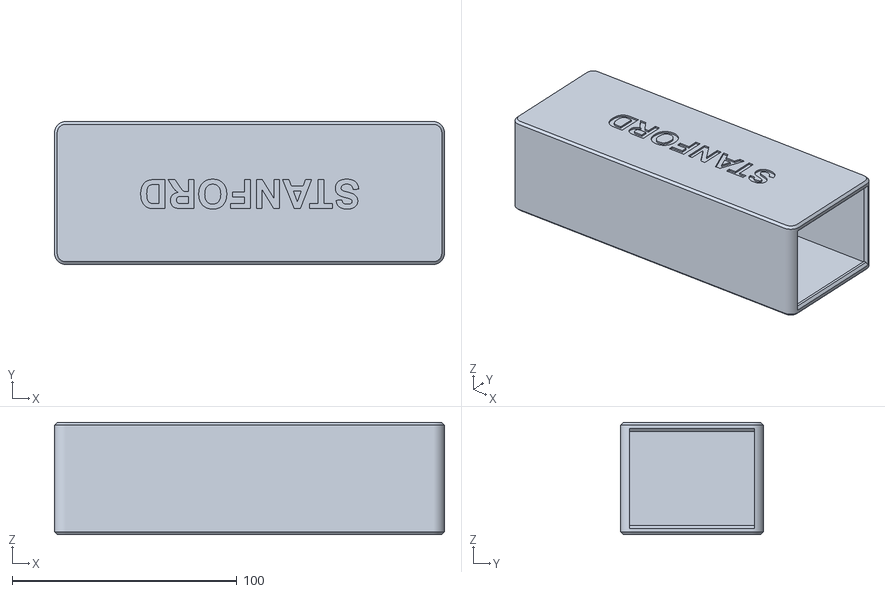
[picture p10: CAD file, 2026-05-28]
cad/housing_phase3.stl
173.6 x 63.6 x 50.0

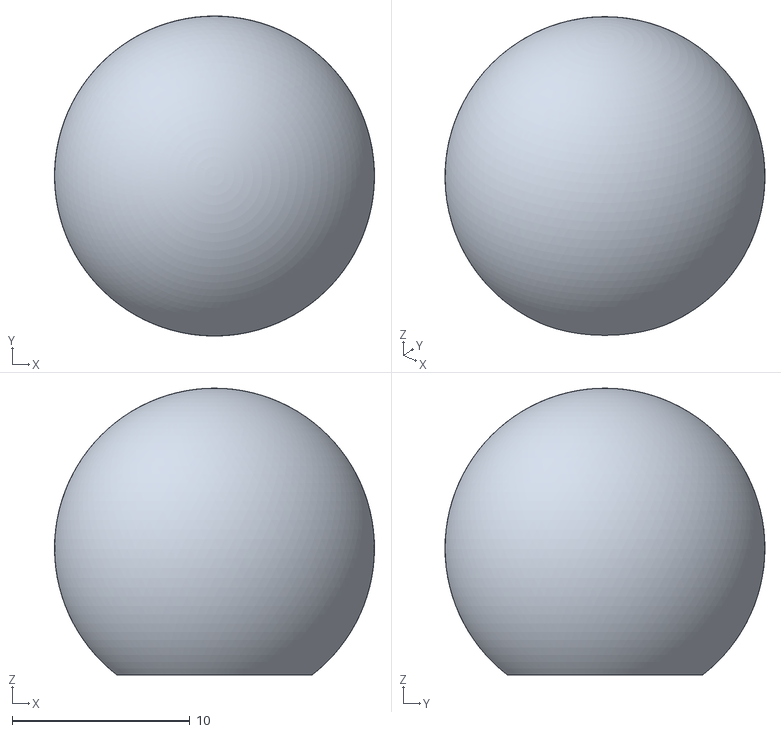
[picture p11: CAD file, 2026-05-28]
cad/joint/Ball 18mm with inner M10 thread.stl
18.0 x 18.0 x 16.1

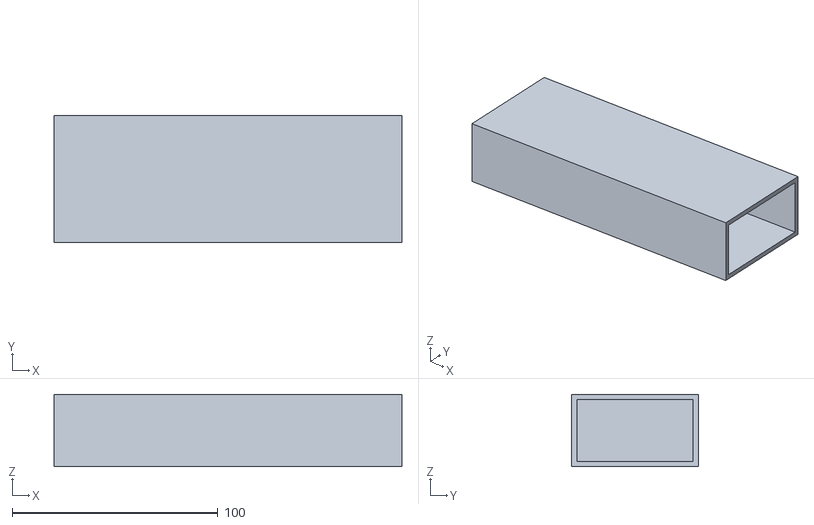
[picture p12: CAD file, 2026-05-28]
cad/housing_phase2.stl
169.1 x 61.6 x 35.0

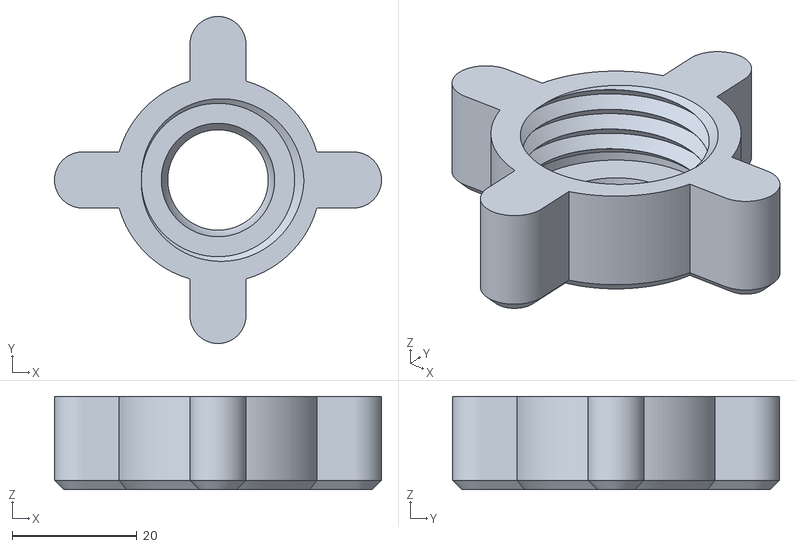
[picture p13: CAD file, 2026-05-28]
cad/final/6_lock_nut.stl
52.5 x 52.5 x 15.0

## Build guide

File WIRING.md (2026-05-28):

# WIRING

**Project:** Contactless Sleep & Environment Monitor
**Companion to:** [TECH-SPEC.md](TECH-SPEC.md)

One card per part. Every pin listed.

## DFRobot C1001 (mmWave radar)

5 V power · UART @ 115200 baud · mounted on the ball-joint outside the housing.

| C1001 pin | Connects to |
|---|---|
| VIN | Feather **USB** pin (5 V passthrough) |
| GND | Breadboard **−** rail (GND) |
| TX | Feather **RX** pin |
| RX | Feather **TX** pin |

## BME680 (temp / humidity / pressure / gas)

3.3 V power · I²C @ default address `0x77`. Adafruit-style breakout: leave **CS and SDO unconnected** (internal pull-ups keep it in I²C mode at the default address).

| BME680 pin | Connects to |
|---|---|
| VIN (or VCC) | Breadboard **+** rail (3 V3) |
| GND | Breadboard **−** rail (GND) |
| SCK | Feather **SCL** |
| SDI | Feather **SDA** |
| SDO | (leave unconnected) |
| CS | (leave unconnected) |

## SPW2430 (analog MEMS microphone)

3.3 V power · analog output, ESP32 ADC1.

| Mic pin | Connects to |
|---|---|
| Vin | Breadboard **+** rail (3 V3) |
| GND | Breadboard **−** rail (GND) |
| DC | Feather **A2** (ADC1) |

## Photoresistor + 3 kΩ (voltage divider)

Analog output, ESP32 ADC1. Three pieces wired together on the breadboard. The 3 kΩ is two 1.5 kΩ resistors in series.

| Divider piece | Connects to |
|---|---|
| Photoresistor leg A | Breadboard **+** rail (3 V3) |
| Photoresistor leg B | Junction row (shared with 3 kΩ and A3) |
| Junction row | Feather **A3** (ADC1) |
| 3 kΩ leg A | Junction row (shared with photoresistor and A3) |
| 3 kΩ leg B | Breadboard **−** rail (GND) |

## Feather V2 — pin usage summary

Plug the Feather across the breadboard's center channel. The pins below are the ones we use; the rest stay unconnected.

| Feather pin | Connects to |
|---|---|
| USB | C1001 VIN (the only 5 V load) |
| 3V3 | Breadboard **+** rail (drives BME680, mic, LDR top) |
| GND | Breadboard **−** rail (shared ground for everything) |
| SDA | BME680 SDI |
| SCL | BME680 SCK |
| TX | C1001 RX |
| RX | C1001 TX |
| A2 | Mic DC |
| A3 | Photoresistor / 3 kΩ junction |

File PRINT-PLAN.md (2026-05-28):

# Print & Assembly Plan

**Date:** 2026-05-26 · **For:** EE284A sleep monitor build · **Companion to:** [PRD.md](PRD.md), [DESIGN.md](DESIGN.md)

## 1. Mechanical System Overview

The C1001 radar mounts to the **front face** of the housing (next to the sensor opening). The GoPro 3-leg is **cropped** to keep only the proven M10 threaded portion + body; the prongs are sliced off and a flat cap is auto-generated. The C1001 holder is an **L-bracket** — horizontal arm is the glue surface, vertical arm holds the C1001 facing outward at 90°.

```
[housing FRONT face]       <- joint plate glued on the left half (52.5 x 27 mm)
   │ epoxy                    sensor window on the right half (39 x 21 mm)
   ▼
[Joint plate]              <- holds the 18mm ball socket
   │ 18mm ball drops in
   ▼
[18mm Ball + M10 thread]
   │ lock nut clamps ball at chosen angle
   ▼
[Lock nut (4 grips)]
   │
   ▼
[Cropped 3-leg adapter]    <- proven M10 threads + flat bottom cap (14.5x14.5 mm)
   │ EPOXY
   ▼
[C1001 L-holder]           <- TOP face of horizontal arm glued to adapter cap
   │                          vertical arm hangs down with pocket on FRONT (+Y)
   ▼
[C1001 PCB in pocket]      <- faces OUTWARD (perpendicular to glue surface)
                              ball joint tilts it down toward the bed
```

## 2. Parts List & Files

| # | Part | Source | File | Size (mm) |
|---|---|---|---|---|
| 1 | Housing | Custom | [cad/housing_phase3.stl](cad/housing_phase3.stl) | 169 × 62 × 50 |
| 2 | C1001 L-holder | Custom | [cad/c1001_holder.stl](cad/c1001_holder.stl) | 30 (w) × 32 (d) × 30 (h) |
| 3 | Ball adapter (cropped 3-leg) | Cropped from downloaded | [cad/ball_adapter_cropped.stl](cad/ball_adapter_cropped.stl) | 14.5 × 14.5 × 22 |
| 4 | Joint plate | Downloaded | [cad/joint/Joint plate for 18mm system.stl](cad/joint/Joint%20plate%20for%2018mm%20system.stl) | 52.5 × 27 × 19.5 |
| 5 | 18 mm Ball | Downloaded | [cad/joint/Ball 18mm with inner M10 thread.stl](cad/joint/Ball%2018mm%20with%20inner%20M10%20thread.stl) | 18 × 18 × 16 |
| 6 | Lock nut | Downloaded | [cad/joint/Lock nut 4 grips for 18mm system.stl](cad/joint/Lock%20nut%204%20grips%20for%2018mm%20system.stl) | 52.5 × 52.5 × 15 |

**Dropped from the build:** the original full GoPro 3-leg connector (replaced by the cropped version which keeps the proven M10 threads + body, drops the prongs).

**Hardware (not printed):**
- 5-min or 24-hour epoxy (two-part)
- Tape / Command strips for wall mount

## 3. Print Order & Settings

Print the small parts first to verify fit, then the housing last. Total time ~12–15 hours.

| # | Part | Time | Orient | Material | Layer | Walls | Infill | Supports |
|---|---|---|---|---|---|---|---|---|
| 1 | C1001 L-holder | ~30 min | Horizontal arm top face DOWN on bed (L upside-down, vertical bar prints upward) | PLA | 0.2 mm | 3 | 25% | No |
| 2 | Ball adapter (cropped) | ~30 min | Flat cap on bed, M10 thread pointing up | PLA | 0.16 mm | 3 | 30% | No |
| 3 | Ball 18 mm | ~30 min | Flat base on bed | PLA | 0.16 mm | 3 | 20% | No |
| 4 | Lock nut | ~45 min | Flat side on bed (thread axis vertical) | PLA | 0.2 mm | 3 | 20% | No |
| 5 | Joint plate | ~1 h | Flat base on bed | PLA | 0.2 mm | 3 | 20% | No |
| 6 | Housing | ~8–10 h | Back face (long unfeatured face) on bed | PLA | 0.2 mm | 3 | 15% gyroid | No |

**Why these specific orientations:**
- **L-holder upside-down**: horizontal arm becomes the print footprint (29.6 × 25 mm), vertical arm extends upward. C1001 pocket prints as a horizontal recess in a vertical wall (no bridging). Cable slot is at the top during print (becomes the bottom in use).
- **Cropped adapter cap-down**: the flat cut cap sits on the bed, M10 threads print upward as a screw thread. Slightly finer layer (0.16 mm) for thread quality.
- **Housing back-on-bed**: sensor window prints as a clean vertical hole (no 39 mm bridge), Stanford deboss prints into a side wall (still legible), open end is a vertical edge.

## 4. Verification Before Final Print

No fit-critical interfaces remain. Just confirm:
- Adapter M10 threads screw into the 18 mm ball cleanly (the threads are from the proven community design).
- L-holder horizontal arm top (29.6 × 25 mm) fully overlaps the adapter cap (14.5 × 14.5 mm) — ample glue area.
- Housing front face has joint plate on the left half, sensor window on the right half, ~38 mm gap between them.

## 5. Assembly Steps

1. **Print all 6 parts per the table above.**
2. **Test-fit the C1001 PCB** into the L-holder pocket from the front — should slide in with light friction, the lip frame catches it. If too tight, bump `c1001_fit` from 0.8 → 1.0 mm in [c1001_holder.py](cad/c1001_holder.py) and reprint.
3. **Glue the joint plate** to the **front face left half** of the housing with epoxy (left of the sensor window).
4. **Drop the 18 mm ball** into the joint plate socket.
5. **Screw the lock nut** down onto the joint plate threading until snug — the ball still tilts but with friction.
6. **Screw the cropped adapter's M10 threads** into the ball's M10 inner hole until tight (these are the proven threads from the community 3-leg design).
7. **Epoxy the L-holder's horizontal-arm top face** to the adapter's flat cap. Center carefully. Let cure overnight before any load.
8. **Slide the C1001 PCB** into the L-holder pocket from the front, route the UART/5V cable out the side slot, around the housing, and into the cavity through the +X open end.
9. **Wire up** the breadboard inside the housing (Feather V2 + BQ24074 + INA219 + boost + BME280 + mic + LDR + LED + button).
10. **Adhere the housing to the wall** with Command strips on the back face.
11. **Aim**: loosen the lock nut, tilt the ball so the C1001 faces the pillow (downward + outward), tighten the lock nut.

## 6. Known Risks & Mitigations

- **C1001 size variance**: PCB tolerance unknown; pocket has 0.8 mm clearance per side. If too tight, bump to 1.0 mm in [c1001_holder.py](cad/c1001_holder.py) and reprint.
- **Ball/socket fit**: the downloaded joint is community-tested; first-time print may need re-printing one piece with adjusted clearance if the ball is too tight in the socket or too loose to clamp.
- **Adapter M10 thread fit**: using the proven community 3-leg threads (cropped). Should screw in cleanly; if too tight, scale the adapter STL down 0.5% in slicer.
- **Epoxy joints**: the C1001 + holder + adapter is light (~10 g), so cured epoxy is more than strong enough. Use 5-min or 24-hour epoxy, **not** superglue — CA glue gets brittle under temperature swings.
- **Housing 8–10 h print**: start it on a stable printer with a fresh nozzle. Single biggest print risk in the build.

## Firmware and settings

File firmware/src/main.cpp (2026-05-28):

#include <Arduino.h>
#include <WiFi.h>
#include <WiFiClientSecure.h>
#include <PubSubClient.h>
#include <ArduinoJson.h>
#include <Wire.h>
#include <Adafruit_Sensor.h>
#include <Adafruit_BME680.h>
#include <DFRobot_HumanDetection.h>
#include "config.h"

constexpr uint8_t MIC_PIN = A2;
constexpr uint8_t LDR_PIN = A3;
constexpr uint16_t MIC_SAMPLES = 1024;
constexpr uint32_t MIC_RATE_HZ = 8000;

Adafruit_BME680 bme;
DFRobot_HumanDetection radar(&Serial1);
WiFiClientSecure net;
PubSubClient mqtt(net);

uint32_t last_publish = 0;
float db_max = 0;

float readDbBurst() {
  uint32_t sum = 0;
  uint16_t samples[MIC_SAMPLES];
  uint32_t step_us = 1000000UL / MIC_RATE_HZ;
  uint32_t t0 = micros();
  for (uint16_t i = 0; i < MIC_SAMPLES; i++) {
    samples[i] = analogRead(MIC_PIN);
    sum += samples[i];
    while (micros() - t0 < (uint32_t)(i + 1) * step_us) {}
  }
  float mean = (float)sum / MIC_SAMPLES;
  float ssq = 0;
  for (uint16_t i = 0; i < MIC_SAMPLES; i++) {
    float d = samples[i] - mean;
    ssq += d * d;
  }
  float rms = sqrtf(ssq / MIC_SAMPLES);
  if (rms < 1) rms = 1;
  return 20.0f * log10f(rms) + MIC_CALIBRATION_DB;
}

void wifiConnect() {
  WiFi.mode(WIFI_STA);
  WiFi.begin(WIFI_SSID, WIFI_PASS);
  while (WiFi.status() != WL_CONNECTED) delay(250);
}

void mqttConnect() {
  while (!mqtt.connected()) {
    if (mqtt.connect(DEVICE_ID, MQTT_USER, MQTT_PASS)) return;
    delay(1000);
  }
}

void publishTelemetry() {
  sSleepComposite c = radar.getSleepComposite();
  uint16_t in_bed = radar.smSleepData(DFRobot_HumanDetection::eInOrNotInBed);

  JsonDocument doc;
  doc["t"]              = (uint32_t)(millis() / 1000);
  doc["dev"]            = DEVICE_ID;
  doc["presence"]       = c.presence;
  doc["in_bed"]         = in_bed;
  doc["sleep_state"]    = c.sleepState;
  doc["breathing"]      = c.averageRespiration;
  doc["heart_rate"]     = c.averageHeartbeat;
  doc["turnover"]       = c.turnoverNumber;
  doc["body_move_large"] = c.largeBodyMove;
  doc["body_move_small"] = c.minorBodyMove;
  doc["apnea_events"]   = c.apneaEvents;
  doc["hum_presence"]   = radar.smHumanData(DFRobot_HumanDetection::eHumanPresence);
  doc["hum_motion"]     = radar.smHumanData(DFRobot_HumanDetection::eHumanMovement);
  doc["hum_range"]      = radar.smHumanData(DFRobot_HumanDetection::eHumanMovingRange);
  doc["hum_dist_cm"]    = radar.smHumanData(DFRobot_HumanDetection::eHumanDistance);

  doc["hr_instant"]     = radar.getHeartRate();
  doc["breath_state"]   = radar.getBreatheState();
  doc["breath_value"]   = radar.getBreatheValue();

  doc["wake_dur"]          = radar.smSleepData(DFRobot_HumanDetection::eWakeDuration);
  doc["light_sleep_dur"]   = radar.smSleepData(DFRobot_HumanDetection::eLightsleep);
  doc["deep_sleep_dur"]    = radar.smSleepData(DFRobot_HumanDetection::eDeepSleepDuration);
  doc["sleep_quality"]     = radar.smSleepData(DFRobot_HumanDetection::eSleepQuality);
  doc["disturbances"]      = radar.smSleepData(DFRobot_HumanDetection::eSleepDisturbances);
  doc["quality_rating"]    = radar.smSleepData(DFRobot_HumanDetection::eSleepQualityRating);
  doc["abnormal_struggle"] = radar.smSleepData(DFRobot_HumanDetection::eAbnormalStruggle);
  doc["unattended_state"]  = radar.smSleepData(DFRobot_HumanDetection::eUnattendedState);
  doc["unattended_time"]   = radar.smSleepData(DFRobot_HumanDetection::eUnattendedTime);

  sSleepStatistics s = radar.getSleepStatistics();
  doc["sleep_score"]      = s.sleepQualityScore;
  doc["sleep_time_min"]   = s.sleepTime;
  doc["shallow_pct"]      = s.shallowSleepPercentage;
  doc["deep_pct"]         = s.deepSleepPercentage;
  doc["time_out_of_bed"]  = s.timeOutOfBed;
  doc["exit_count"]       = s.exitCount;
  doc["turnover_total"]   = s.turnOverCount;

  if (bme.performReading()) {
    doc["temp_c"]       = bme.temperature;
    doc["humidity"]     = bme.humidity;
    doc["pressure_hpa"] = bme.pressure / 100.0f;
    doc["gas_ohm"]      = bme.gas_resistance;
  }
  doc["db_spl"]         = db_max;
  doc["light_raw"]      = analogRead(LDR_PIN);

  char buf[1024];
  size_t n = serializeJson(doc, buf);
  mqtt.publish(MQTT_TOPIC, buf, n);
}

void setup() {
  Serial.begin(115200);
  Serial1.begin(115200);

  Wire.begin();
  bme.begin();
  bme.setTemperatureOversampling(BME680_OS_8X);
  bme.setHumidityOversampling(BME680_OS_2X);
  bme.setPressureOversampling(BME680_OS_4X);
  bme.setIIRFilterSize(BME680_FILTER_SIZE_3);
  bme.setGasHeater(320, 150);

  radar.begin();
  radar.configWorkMode(DFRobot_HumanDetection::eSleepMode);
  radar.sensorRet();

  analogReadResolution(12);

  wifiConnect();
  net.setInsecure();
  mqtt.setServer(MQTT_HOST, MQTT_PORT);
  mqtt.setBufferSize(1024);
  mqttConnect();
}

void loop() {
  if (WiFi.status() != WL_CONNECTED) wifiConnect();
  if (!mqtt.connected()) mqttConnect();
  mqtt.loop();

  float db = readDbBurst();
  if (db > db_max) db_max = db;

  if (millis() - last_publish >= PUBLISH_INTERVAL_MS) {
    publishTelemetry();
    db_max = 0;
    last_publish = millis();
  }
}

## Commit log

2026-05-28 Initial commit: docs, firmware scaffold, web scaffold, CAD files
    [1_housing.stl, 2_c1001_holder.stl, 4_joint_plate.stl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]
2026-05-28 Drop SGP30 + LED; inline DB schema for production migration
2026-05-28 C1001: send instant vitals + bed-state queries + session statistics (all fields)
2026-05-28 Telemetry table: all 40 fields + filter dropdown by sensor group
2026-05-28 Dashboard: bump /api/nights limit from 30 to 365 for calendar heatmap
2026-05-28 Dashboard: add /api/today endpoint for in-progress slot
2026-05-28 Dashboard: add slot model and PST date helpers
2026-05-28 Dashboard: extract StageBand component with new stage palette
2026-05-28 Dashboard: rewrite page as slot-based night viewer
2026-05-28 Dashboard: add am/pm hour markers under sleep stage band
2026-05-28 Dashboard: use sensor-derived totals for time sleeping + awake in bed
2026-05-28 Dashboard: clamp chart Y axes (temp/humidity/pressure) so tiny swings don't dominate
2026-05-28 Dashboard: drop redundant sensor score stat (keep sleep quality)
2026-05-29 Flesh out per-slide content for final presentation outline
    Add hard-clinical stat trio (with sources), comparison-table rows/columns,
    eldercare vision framing, per-slide content decisions for all 17 slides,
    and a dedicated enclosure slide (deck now 17 slides + live demo).
2026-05-29 Local dev: also disable SSL for Railway TCP proxy hosts
2026-05-29 Add top-down tree diagrams for slides 5 & 6 (system design)
    Slide 5: nurse-station triage tree (root -> ranked room leaves).
    Slide 6: architecture tree (dashboard -> cloud -> broker -> node xN -> sensors).
    Bookish x mineral palette, 1280x720 export frames, self-contained HTML.
2026-05-29 Refine slide 5/6 diagrams: sleep-score-first leaves, upward flow, no prose
    - Slide 5 leaves: sleep score as hero number + 'Room NNN' sublabel
    - Slide 6: upward arrowheads so data visibly flows up the tree
    - Remove all narrator text (kicker/headline/subhead/caption/footnote); center trees
2026-05-29 Add node block diagram (hub-and-spoke, real pins/wiring from WIRING.md)
2026-05-29 Node diagram: drop I2C 0x77 (code uses library default, never references it)
2026-05-29 Fix time-sleeping stat latching onto sensor glitch spike
    light/deep/wake are cumulative per-night counters; use the end-of-night
    value (lastField) instead of max(), which latched onto an occasional
    glitch spike (e.g. 20563) and rendered "342h 43m".
